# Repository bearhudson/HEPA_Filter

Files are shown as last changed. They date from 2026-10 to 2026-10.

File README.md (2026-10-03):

The following is from Gemini based on source generated from Claude, so I have no idea if it's correct. I am not in any way versed in fluid dynamics enough to understand if this is correct, true, or even moderately sensible. I am going to make one, which should make it self evident if it works or not by checking the filter for dinge.

<p align="center">
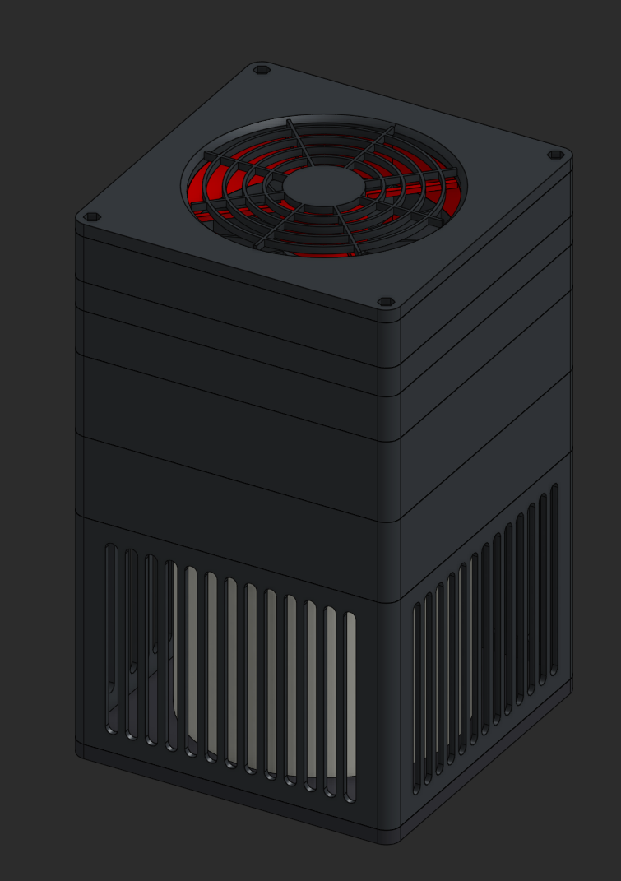
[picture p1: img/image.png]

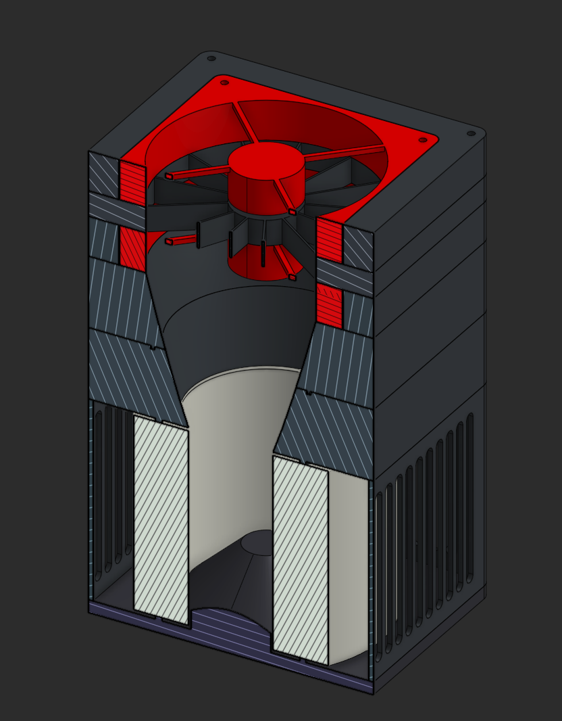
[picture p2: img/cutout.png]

</p>
--------

# Series-Stacked HEPA Purifier (Dual 140mm)

A 3D-printed, high-efficiency room air purifier utilizing a cylindrical HEPA filter and two 140mm High Static Pressure (HSP) PC fans in a series-stacked configuration. 

If you've researched DIY air purifiers online, you've likely encountered a common claim: *"PC fans cannot push air through a HEPA filter because they don't generate enough static pressure."* 

This README breaks down the fluid dynamics and math proving why that claim is based on a misunderstanding of system impedance, and how series-stacking, swirl recovery, and acoustic tuning solve the problem.

---

## The Myth: "PC Fans Lack the Pressure for HEPA"

The skepticism online stems from comparing two mismatched static figures:
1. **The Filter's Rated Pressure Drop:** A standard pleated filter might list a pressure drop of $250 \text{ Pa}$ ($1.0 \text{ mmH}_2\text{O}$).
2. **The Fan's Rated Static Pressure:** A premium 140mm PC fan might max out at $25 \text{ Pa}$ ($2.5 \text{ mmH}_2\text{O}$).

If $25 \text{ Pa} < 250 \text{ Pa}$, the fan stalls, right? **Wrong.** 

This assumes the filter's pressure drop is a static, unchanging wall. In reality, a filter's resistance is a curve that depends entirely on airflow. The $250 \text{ Pa}$ rating is usually calculated at an HVAC system's flow rate of **300+ CFM**. We are targeting **40 to 60 CFM** for a single room.

### 1. The Math of Filter Resistance (System Impedance)
Airflow through the densely packed micro-glass fibers of a HEPA filter is strictly in the **laminar flow regime**. According to Darcy's Law for porous media, pressure drop ($\Delta P$) in laminar flow scales *linearly* with velocity (and therefore volumetric flow rate, $Q$):

$$ \Delta P = R \cdot Q $$

If a filter creates $250 \text{ Pa}$ of resistance at $300 \text{ CFM}$, we can find its resistance coefficient ($R$):

$$ R = \frac{250 \text{ Pa}}{300 \text{ CFM}} = 0.833 \text{ Pa/CFM} $$

If we only need $60 \text{ CFM}$ to achieve 4.5 Air Changes per Hour (ACH) in a 100 sq ft room, the actual pressure drop we must overcome is:

$$ \Delta P_{target} = 0.833 \cdot 60 = 50 \text{ Pa} $$

A single 140mm PC fan maxing out at $25 \text{ Pa}$ still cannot overcome this. This is where the series stack comes in.

### 2. The Math of Series Stacking
When fans are placed side-by-side (parallel), their volumetric flow ($Q$) adds together, but their pressure limit ($\Delta P$) remains the same. When fans are placed front-to-back (**series**), their volumetric flow remains the same, but their **static pressure limits add together**.

$$ \Delta P_{total} = \Delta P_1 + \Delta P_2 $$

Two $25 \text{ Pa}$ fans in series generate a maximum static pressure of **$50 \text{ Pa}$**. 

By plotting the combined fan curve (which slopes down as flow increases) against the filter's linear impedance curve (which slopes up as flow increases), the lines intersect at the **Operating Point**. Two 140mm HSP fans in series shift the pressure curve high enough to intersect the filter's impedance curve right at our $40 \text{-} 60 \text{ CFM}$ target.

---

## Aerodynamic Optimizations

Brute-forcing pressure isn't enough; the air must be managed efficiently to prevent turbulence and stalling. This design incorporates three specific aerodynamic features:

### The 12-Degree Diffuser
Air exiting the $94\text{ mm}$ inner bore of the filter must expand to hit the $132\text{ mm}$ swept area of the 140mm fans. If the transition is an abrupt flat step, flow separates, creating a low-pressure vortex that acts like a solid wall, artificially increasing system impedance. 
* This design uses a **$12^\circ$ half-angle conical diffuser**. Fluid dynamics dictates that a divergence angle under $15^\circ$ prevents boundary layer separation, allowing kinetic energy to efficiently convert back to static pressure before hitting the first fan.

### The Swirl Straightener
Axial fans impart a corkscrew rotation (swirl) to the air. If Fan 1 feeds directly into Fan 2, Fan 2's blades are hitting air that is already rotating in the same direction. This effectively reduces Fan 2's relative angle of attack to zero, rendering it useless. 
* Between the two fans is a **16mm deep, 13-vane stator**. It recovers the rotational kinetic energy of Fan 1, converting it into axial static pressure, and feeds non-rotating air into Fan 2 so it can bite the air and multiply the pressure curve properly. (13 is a prime number to prevent harmonic tonal resonance with standard 7- or 9-blade fan rotors).

### Acoustic Tuning (PWM Offset)
When two identical motors spin at the exact same RPM in a shared structural tube, they drift in and out of phase, creating a loud, pulsing harmonic hum (beating). 
* The custom ESP32 firmware drives the two fans on independent PWM channels. Fan 2 is mathematically offset to run **10% faster** than Fan 1. This prevents phase-locking and completely eliminates the beating frequency, resulting in a smooth, steady white noise.

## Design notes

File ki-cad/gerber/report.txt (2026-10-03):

Plotted to '/Users/brian/gits/HEPA_Filter/ki-cad/board/board-F_Cu.gbr'.
Plotted to '/Users/brian/gits/HEPA_Filter/ki-cad/board/board-B_Cu.gbr'.
Plotted to '/Users/brian/gits/HEPA_Filter/ki-cad/board/board-F_Paste.gbr'.
Plotted to '/Users/brian/gits/HEPA_Filter/ki-cad/board/board-B_Paste.gbr'.
Plotted to '/Users/brian/gits/HEPA_Filter/ki-cad/board/board-F_Silkscreen.gbr'.
Plotted to '/Users/brian/gits/HEPA_Filter/ki-cad/board/board-B_Silkscreen.gbr'.
Plotted to '/Users/brian/gits/HEPA_Filter/ki-cad/board/board-F_Mask.gbr'.
Plotted to '/Users/brian/gits/HEPA_Filter/ki-cad/board/board-B_Mask.gbr'.
Plotted to '/Users/brian/gits/HEPA_Filter/ki-cad/board/board-Edge_Cuts.gbr'.
Created Gerber job file '/Users/brian/gits/HEPA_Filter/ki-cad/board/board-job.gbrjob'.
Info: Done.

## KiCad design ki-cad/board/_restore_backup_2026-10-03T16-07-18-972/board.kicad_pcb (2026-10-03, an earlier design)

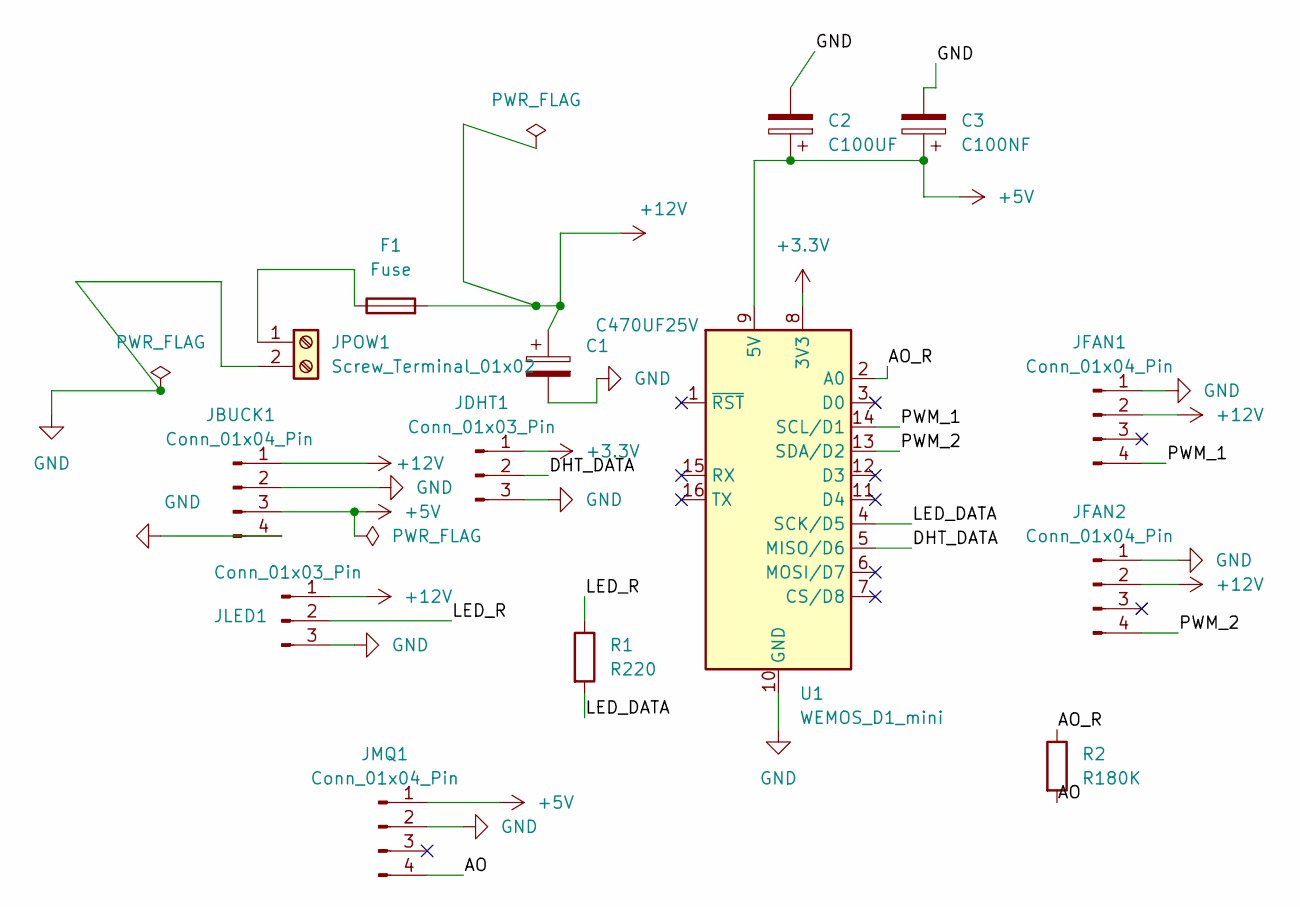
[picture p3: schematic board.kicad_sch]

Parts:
C1: C470UF25V; CP_Radial_D8.0mm_P3.50mm
C2: C100UF; CP_Radial_D8.0mm_P3.50mm
C3: C100NF; C_Disc_D4.3mm_W1.9mm_P5.00mm
F1: Fuse; Fuseholder_Blade_ATO_Littelfuse_Pudenz_2_Pin
JBUCK1: Conn_01x04_Pin; PinHeader_1x04_P2.54mm_Vertical
JDHT1: Conn_01x03_Pin; PinHeader_1x03_P2.54mm_Vertical
JFAN1, JFAN2: Conn_01x04_Pin; FanPinHeader_1x04_P2.54mm_Vertical
JLED1: Conn_01x03_Pin; JST_XH_B3B-XH-A_1x03_P2.50mm_Vertical
JMQ1: Conn_01x04_Pin; PinHeader_1x04_P2.54mm_Vertical
JPOW1: Screw_Terminal_01x02; TerminalBlock_Phoenix_MKDS-1,5-2-5.08_1x02_P5.08mm_Horizont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
R1: R220; R_Axial_DIN0207_L6.3mm_D2.5mm_P7.62mm_Horizontal
R2: R180K; R_Axial_DIN0207_L6.3mm_D2.5mm_P7.62mm_Horizontal
U1: WEMOS_D1_mini; WEMOS_D1_mini_light

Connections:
+3.3V: JDHT1.1, U1.8 (3V3)
+5V: C2.1, C3.1, JBUCK1.3, JMQ1.1, U1.9 (5V)
+12V: C1.1, F1.2, JBUCK1.1, JFAN1.2, JFAN2.2, JLED1.1
/AO: JMQ1.4, R2.2
/AO_R: R2.1, U1.2 (A0)
/DHT_DATA: JDHT1.2, U1.5 (MISO/D6)
/LED_DATA: R1.2, U1.4 (SCK/D5)
/LED_R: JLED1.2, R1.1
/PWM_1: JFAN1.4, U1.14 (SCL/D1)
/PWM_2: JFAN2.4, U1.13 (SDA/D2)
GND: C1.2, C2.2, C3.2, JBUCK1.2, JBUCK1.4, JDHT1.3, JFAN1.1, JFAN2.1, JLED1.3, JMQ1.2, JPOW1.2, U1.10 (GND)
unnamed: F1.1, JPOW1.1

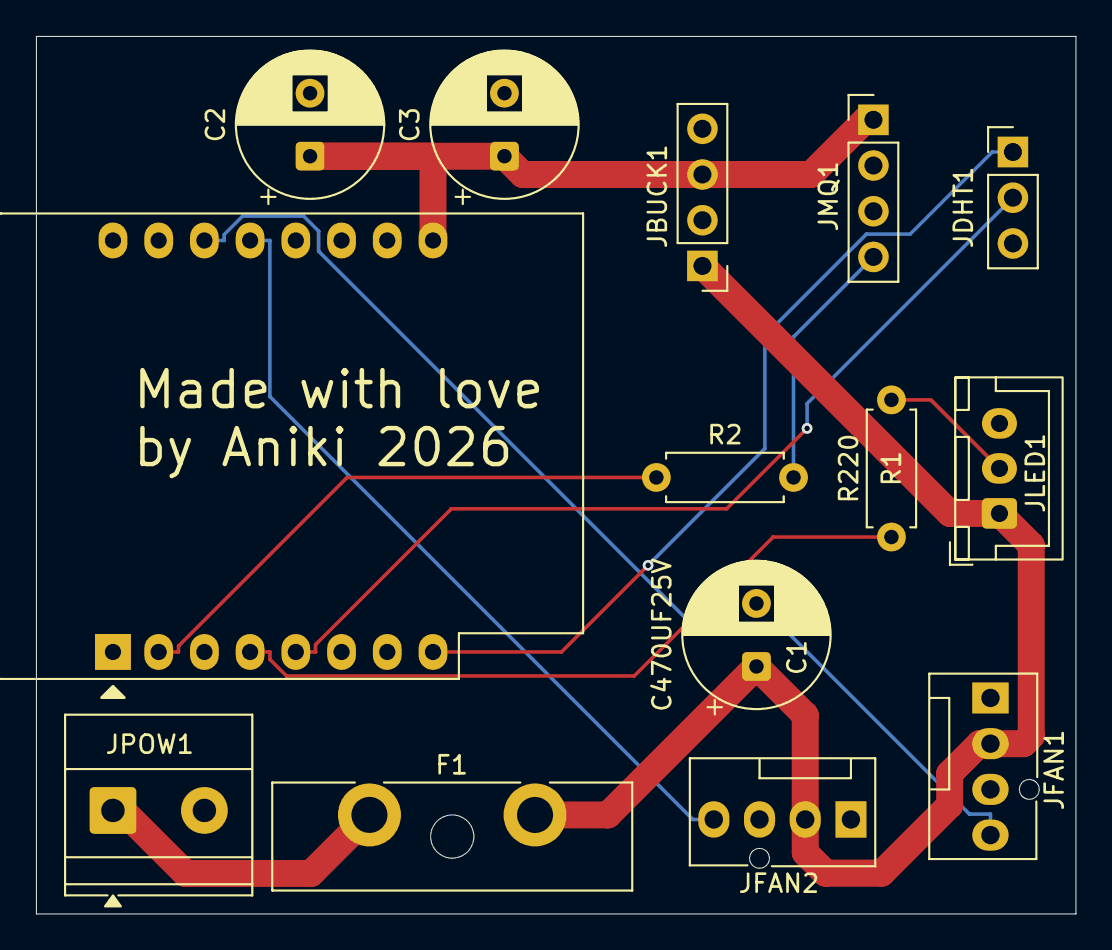
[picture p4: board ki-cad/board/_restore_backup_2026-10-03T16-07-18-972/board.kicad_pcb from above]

Board: 2 copper layers, 57.8 x 48.8 mm, 14 parts (0 on the bottom side), 12 nets.

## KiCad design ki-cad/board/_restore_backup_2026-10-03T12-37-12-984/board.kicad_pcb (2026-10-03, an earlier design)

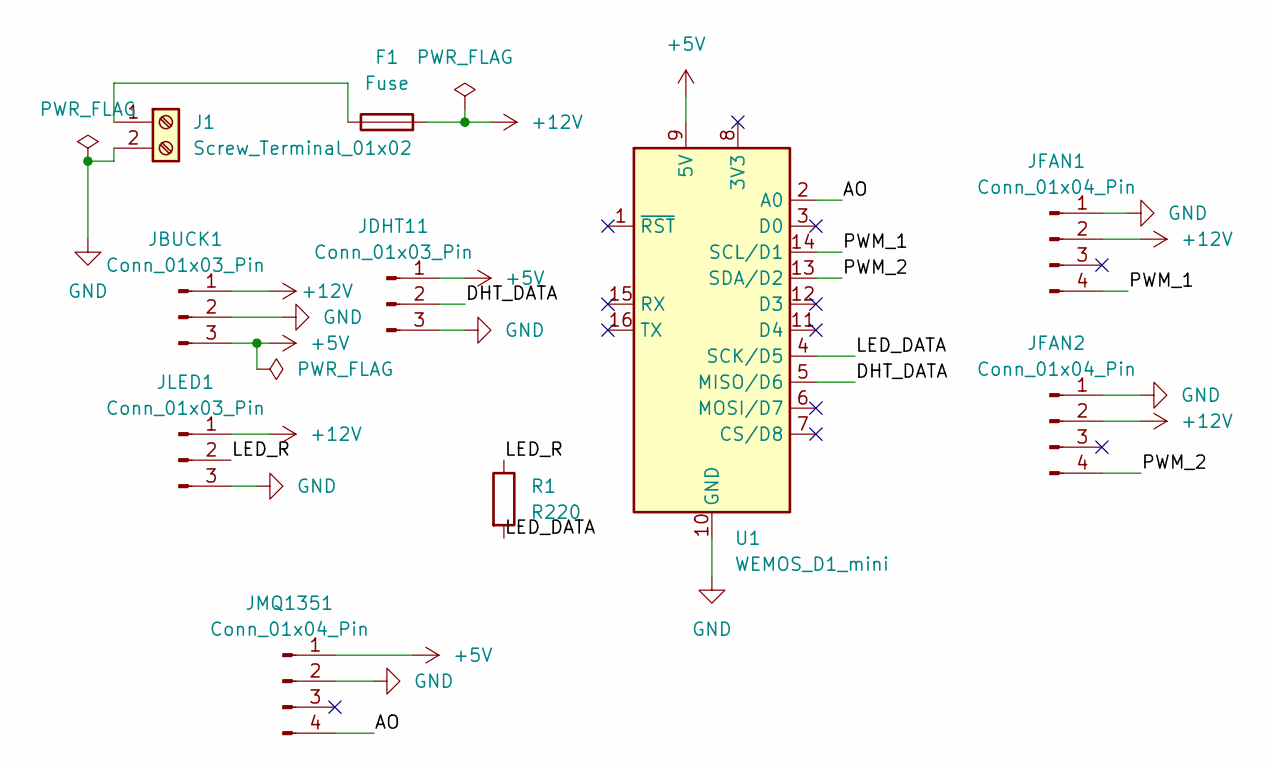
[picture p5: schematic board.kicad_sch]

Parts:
F1: Fuse; Fuse_Blade_ATO_directSolder
J1: Screw_Terminal_01x02; TerminalBlock_Phoenix_MKDS-1,5-2-5.08_1x02_P5.08mm_Horizont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
JBUCK1: Conn_01x03_Pin; PinHeader_1x03_P2.54mm_Vertical
JDHT11: Conn_01x03_Pin; PinHeader_1x03_P2.54mm_Vertical
JFAN1, JFAN2: Conn_01x04_Pin; Molex_KK-254_AE-6410-04A_1x04_P2.54mm_Vertical
JLED1: Conn_01x03_Pin; PinHeader_1x03_P2.54mm_Vertical
JMQ1351: Conn_01x04_Pin; PinHeader_1x04_P2.54mm_Vertical
R1: R220; R_Axial_DIN0207_L6.3mm_D2.5mm_P7.62mm_Horizontal
U1: WEMOS_D1_mini; WEMOS_D1_mini_light

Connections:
+5V: JBUCK1.3, JDHT11.1, JMQ1351.1, U1.9 (5V)
+12V: F1.2, JBUCK1.1, JFAN1.2, JFAN2.2, JLED1.1
/AO: JMQ1351.4, U1.2 (A0)
/DHT_DATA: JDHT11.2, U1.5 (MISO/D6)
/LED_DATA: R1.2, U1.4 (SCK/D5)
/LED_R: JLED1.2, R1.1
/PWM_1: JFAN1.4, U1.14 (SCL/D1)
/PWM_2: JFAN2.4, U1.13 (SDA/D2)
GND: J1.2, JBUCK1.2, JDHT11.3, JFAN1.1, JFAN2.1, JLED1.3, JMQ1351.2, U1.10 (GND)
unnamed: F1.1, J1.1

Board: 2 copper layers, 10 parts (0 on the bottom side), 10 nets, no tracks yet.

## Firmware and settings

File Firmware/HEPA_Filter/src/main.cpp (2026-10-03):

#include <Arduino.h>
#include <DHT.h>
#include <Adafruit_NeoPixel.h>

// --- Pin Definitions ---
const int MQ135_PIN = A0;   // MQ-135 Analog out
const int FAN1_PIN  = 5;    // D1 on NodeMCU/Wemos (Intake Fan)
const int FAN2_PIN  = 4;    // D2 on NodeMCU/Wemos (Exhaust Fan)
const int LED_PIN   = 14;   // D5 on NodeMCU/Wemos (WS2812B Data)
const int DHT_PIN   = 12;   // D6 on NodeMCU/Wemos (DHT11 Data)

// --- Constants & Tuning ---
const int NUM_LEDS = 10;           // Total LEDs on your strip
const int LED_INTENSITY = 51;      // 20% brightness (out of 255)

const float FAN2_OFFSET = 1.10;    // Fan 2 runs 10% faster to prevent acoustic beating
const int MIN_FAN_SPEED = 255;     // ~25% duty cycle baseline (keeps air moving)
const int MAX_FAN_SPEED = 1023;    // 100% duty cycle limit for ESP8266

// MQ-135 thresholds (You may need to tweak these based on your room's baseline)
const float CLEAN_AIR_ADC = 150.0; // Typical ADC reading in clean air
const float POOR_AIR_ADC = 600.0;  // Typical ADC reading when polluted

// --- Object Initialization ---
DHT dht(DHT_PIN, DHT11);
Adafruit_NeoPixel strip(NUM_LEDS, LED_PIN, NEO_GRB + NEO_KHZ800);

// Timing state
unsigned long lastSensorRead = 0;
const unsigned long SENSOR_INTERVAL = 2000; // Read sensors every 2 seconds

// System state
int currentFanSpeed = MIN_FAN_SPEED;
int currentAQI = 0; // 0 (Good) to 100 (Bad)


// Calculates the MQ135 temperature & humidity correction factor
// Based on the standard datasheet polynomial fit normalized to 20C and 33% RH
float getMQ135CorrectionFactor(float temp, float hum) {
  return (0.00035 * temp * temp) - (0.02718 * temp) + 1.3753 - (hum - 33.0) * 0.0018;
}


void setup() {
  Serial.begin(115200);
  
  // Setup Fans (25kHz PWM frequency for PC fans)
  analogWriteFreq(25000);
  pinMode(FAN1_PIN, OUTPUT);
  pinMode(FAN2_PIN, OUTPUT);
  
  // Setup Sensors and LEDs
  dht.begin();
  strip.begin();
  strip.setBrightness(LED_INTENSITY);
  strip.show(); // Initialize all pixels to 'off'
}


void loop() {
  unsigned long currentMillis = millis();

  // 1. Read Sensors (Non-blocking loop)
  if (currentMillis - lastSensorRead >= SENSOR_INTERVAL) {
    lastSensorRead = currentMillis;

    float humidity = dht.readHumidity();
    float tempC = dht.readTemperature();
    int rawADC = analogRead(MQ135_PIN);

    // Apply correction factor if DHT11 readings are valid
    float correctedADC = rawADC;
    if (!isnan(humidity) && !isnan(tempC)) {
      float cf = getMQ135CorrectionFactor(tempC, humidity);
      correctedADC = rawADC * cf; 
    }

    // 2. Calculate Air Quality Index (0-100)
    currentAQI = map(correctedADC, CLEAN_AIR_ADC, POOR_AIR_ADC, 0, 100);
    currentAQI = constrain(currentAQI, 0, 100);

    // 3. Determine Target Fan Speed
    currentFanSpeed = map(currentAQI, 0, 100, MIN_FAN_SPEED, MAX_FAN_SPEED);
    
    // Serial monitor debugging
    Serial.printf("T: %.1fC | H: %.1f%% | Raw ADC: %d | Corr ADC: %.1f | AQI: %d | Fan1: %d\n", 
                  tempC, humidity, rawADC, correctedADC, currentAQI, currentFanSpeed);
  }

  // 4. Update Hardware PWM
  int fan2Speed = (int)(currentFanSpeed * FAN2_OFFSET);
  if (fan2Speed > 1023) {
      fan2Speed = 1023; // Prevent 10-bit overflow
  }
  analogWrite(FAN1_PIN, currentFanSpeed);
  analogWrite(FAN2_PIN, fan2Speed);

  // 5. Update LED Strip
  // Map AQI to a Green -> Yellow -> Red gradient
  int r = 0, g = 0, b = 0;
  if (currentAQI <= 50) {
    g = 255;
    r = map(currentAQI, 0, 50, 0, 255); // Ramps up Red to make Yellow
  } else {
    r = 255;
    g = map(currentAQI, 50, 100, 255, 0); // Ramps down Green to make pure Red
  }

  // Map the current fan speed to the number of lit LEDs
  int ledsToLight = map(currentFanSpeed, MIN_FAN_SPEED, MAX_FAN_SPEED, 1, NUM_LEDS);

  strip.clear();
  for (int i = 0; i < ledsToLight; i++) {
    strip.setPixelColor(i, strip.Color(r, g, b));
  }
  strip.show();

  // 10ms delay to keep the main loop stable
  delay(10);
}

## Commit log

2026-10-03 Adding DHT11 and MQ135 support for fan speed calculation
2026-10-03 Adding ki-cad work.
    [board-B_Cu.gbr, board-B_Mask.gbr, board-B_Paste.gbr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]
2026-10-05 latest ki-cads
    [board-B_Cu.gbr, board-B_Mask.gbr, board-B_Paste.gbr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]
